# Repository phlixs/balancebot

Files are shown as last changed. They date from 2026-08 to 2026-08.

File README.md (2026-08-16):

# BalanceBot

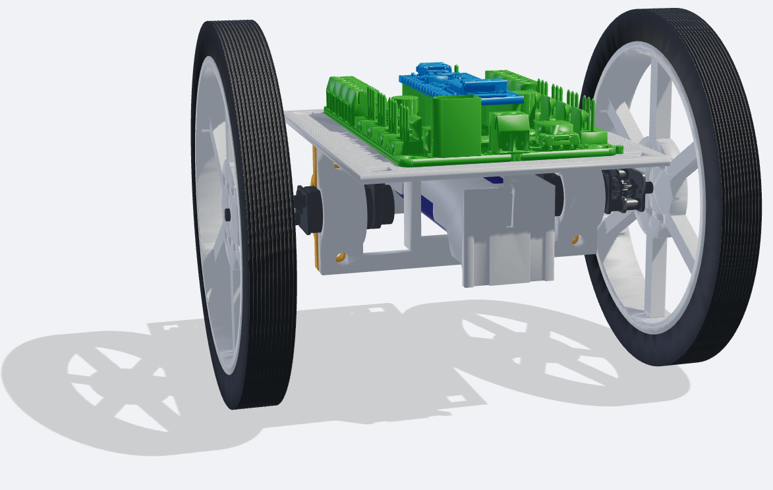
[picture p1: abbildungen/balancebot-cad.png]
Der BalanceBot als CAD-Baugruppe: zwei 90-mm-Räder auf einer Achse, dazwischen der 3D-gedruckte Rahmen mit dem Nano Motor Carrier und dem Arduino Nano 33 IoT auf der Trägerplatte, darunter die Motorhalter mit den N20-Getriebemotoren und dem 18650-Akku.


Ein zweirädriger selbstbalancierender Roboter (inverses Pendel) auf Basis
eines **Arduino Nano 33 IoT** mit **Nano Motor Carrier**.

Die Motivation hinter diesem Projekt ist es, aus den vorhandenen Komponenten
des **Arduino Engineering Kit Rev2** einen vollständig quelloffenen Roboter zu
entwickeln. Wer das Kit besitzt, kann damit den nächsten Schritt gehen und
erhält eine nachhaltige, lizenzunabhängige Engineering-Lösung.

Die Firmware ist in C++ geschrieben und wird mit **PlatformIO** gebaut. Die
Auswertekette ist Python. Der Rahmen ist ein Eigenentwurf in **FreeCAD** und
für den 3D-Druck ausgelegt.

---

## Sicherheit — vor dem ersten Einschalten lesen

Diese Regeln sind nicht kosmetisch. Der Motortreiber des Nano Motor Carrier
ist für **500 mA** ausgelegt, der **Stallstrom der N20-Motoren beträgt
1.03 A**. Ein blockierter Motor bei vollem Duty zerstört den Treiber.

1. **Bei jedem Motortest sind die Räder in der Luft.** Bot aufbocken, so dass
   die Räder frei drehen. Bodenkontakt erst, wenn der Regelkreis am Gerät
   erprobt ist — dann auf freier Fläche und in Bodennähe.
2. **Kein Motorbetrieb ohne erfolgreiche Initialisierung** von Motor Carrier
   und IMU. Schlägt eine davon fehl, bleibt die Firmware im Zustand `E_STOP`
   und gibt keine Stellgröße aus.
3. **Vor jedem Bodenversuch die Akkuspannung prüfen.** Die Stellwirkung
   skaliert direkt mit ihr. Unter **3.3 V** sind die Reglerparameter nicht
   mehr gültig.
4. **`MAX_DUTY` nicht erhöhen.** Die 45 % in `src/balance/config.h` sind die
   Ableitung aus 0.50 A / 1.03 A = 48.5 %, konservativ abgerundet.

### Hartgrenzen in der Firmware

Alle Werte in `Balancebot_code/src/balance/config.h`. Sie sind gerechnet oder
gemessen, nicht geraten:

| Parameter | Wert | Wofür |
|---|---|---|
| `MAX_DUTY` | 45 % | Stromgrenze des Treibers. Überschreiten zerstört ihn. |
| `FALLEN_ANGLE_DEG` | 45° | Sicherheitsabschaltung. Motoren stromlos. |
| `RECOVERY_ANGLE_DEG` | 15° | Rückkehr aus `FALLEN` erst unterhalb dieses Winkels. |
| `SATURATION_TIMEOUT_MS` | 1000 ms | Dauersättigung heißt, der Bot kann sich nicht mehr fangen. |
| `LOOP_OVERRUN_MS` | 50 ms | Ein Zyklus länger als fünf Perioden → die Regelung war blind → `E_STOP`. |
| `IMU_STALE_CYCLES` | 50 (500 ms) | Eingefrorene IMU-Werte → `E_STOP`. |
| `LOOP_PERIOD_MS` | 10 ms | Unterschreiten überläuft das I2C-Budget (6.4 ms Mittel, 8.3 ms worst case). |

### Die gemessenen Parameter gelten für *diesen* Aufbau

Wer den Bot nachbaut, bekommt einen anderen Rahmen, eine andere
Massenverteilung und andere Motoren aus der Serienstreuung. Diese Werte
müssen **neu gemessen**, nicht übernommen werden:

| Parameter | Hier gemessen | Bei falschem Wert |
|---|---|---|
| `DEADZONE_DUTY_POS` / `_NEG` | 23 % / 17 % bei 3.57 V | Schwingen, Gierzucken oder kein Anlaufen |
| `COG_HEIGHT_M` | Schwerpunkthöhe, Auslenkungsmethode | Modell und Verstärkungen falsch ausgelegt |
| `TOTAL_MASS_KG` | gewogen | dito |
| `KP_ANGLE`, `KD_ANGLE` | Polvorgabe aus dem gemessenen Modell, auf Totzeit herabgesetzt | Grenzzyklus oder zu träges Fangen |

Die Asymmetrie der Totzone (23 % vorwärts gegen 17 % rückwärts) liegt am
Treiber des Carriers, nicht am Motor — deshalb wird sie pro Duty-Vorzeichen
kompensiert.

> **Wenn es schwingt, nicht `KD_ANGLE` erhöhen.** Bei totzeitbedingten
> Schwingungen senkt mehr D-Anteil die kritische Totzeit zusätzlich. Der
> übliche Reflex ist hier falsch. `KI_ANGLE` bleibt 0, bis der PD-Regler
> stabil steht.

---

## Hardware

Vollständig aus dem Arduino Engineering Kit Rev2, nichts zugekauft:

| Teil | Typ |
|---|---|
| Mikrocontroller | Arduino Nano 33 IoT (SAMD21) |
| Motortreiber | Arduino Nano Motor Carrier |
| IMU | BNO055, I2C, Sensorfusion auf dem Chip |
| Motoren | 2 × N20-Getriebemotoren, 100:1 |
| Encoder | 2 × magnetisch, 1200 Counts pro Radumdrehung |
| Räder | Pololu, 90 mm |
| Akku | 1 × 18650 Li-Ion, nominal 3.7 V |
| Rahmen | Eigenentwurf, FreeCAD, 3D-Druck |

---

## Aufbau des Repos

```
Balancebot_code/
  src/balance/        Modulare Firmware — aktive Entwicklung
  src/balance.cpp     balance_v1, monolithische Referenzfassung
  src/tests/          Testsketche: hw_check, carrier_timing,
                      imu_latency, deadzone_id
  test/               Native Unit-Tests (Unity, laufen ohne Hardware)
  python/             Messkette: acquire → process → analyze
  messungen/results/  Kuratierte Messprotokolle der Inbetriebnahme
CAD_BalanceBot/       FreeCAD-Baugruppe, STEP-Modelle, CoM-Analyse
```

---

## Werkzeuge einrichten

Gebraucht werden **Python 3.11+** und **PlatformIO**. PlatformIO lädt die
Toolchain für den SAMD21 und die Bibliotheken beim ersten Build selbst.

**Linux**

```bash
python3 -m venv .venv
.venv/bin/pip install platformio
.venv/bin/pip install -r Balancebot_code/python/requirements.txt
```

**Windows (PowerShell)**

```powershell
py -m venv .venv
.venv\Scripts\pip install platformio
.venv\Scripts\pip install -r Balancebot_code\python\requirements.txt
```

---

## Bauen, flashen, beobachten

Alle Firmware-Kommandos laufen **aus `Balancebot_code/`** und sind auf beiden
Plattformen identisch:

| Zweck | Kommando |
|---|---|
| Firmware bauen | `pio run -e balance` |
| Flashen | `pio run -e balance -t upload` |
| Serieller Monitor | `pio device monitor -e balance` |
| Unit-Tests (ohne Hardware) | `pio test -e native` |
| Alle Umgebungen bauen | `pio run -e balance -e balance_v1 -e hw_check -e carrier_timing -e imu_latency -e deadzone_id` |

Unterschiedlich ist nur der serielle Port: Linux `/dev/ttyACM*` — die Nummer
wechselt nach jedem Aus- und Einschalten —, Windows `COM*`. Bei den
Python-Skripten `--port` deshalb immer explizit angeben:

```bash
python Balancebot_code/python/acquire.py --port /dev/ttyACM0   # Linux
```

```powershell
python Balancebot_code\python\acquire.py --port COM3           # Windows
```

> **`-e balance` beim Monitor ist nicht optional.** Ohne Umgebung greift
> `monitor_speed` aus der `[common]`-Sektion nicht, und PlatformIO fällt auf
> 9600 Baud zurück — die Ausgabe ist dann unlesbar.

### Verfügbare Build-Umgebungen

| Umgebung | Was sie tut |
|---|---|
| `balance` | Modulare Regelung, aktiver Stand |
| `balance_v1` | Erste funktionierende PID-Fassung, Referenz |
| `hw_check` | Interaktives Serial-Menü zur Hardware-Prüfung |
| `carrier_timing` | Misst die I2C-Latenz aller Carrier-Aufrufe |
| `imu_latency` | Misst die Dauer eines BNO055-`getEvent()` |
| `deadzone_id` | Rampt Duty hoch und loggt die Anlaufschwelle |
| `native` | Unit-Tests auf dem PC, ohne Hardware |

---

## Erste Inbetriebnahme

**Räder in der Luft.** Der Reihe nach:

1. **Unit-Tests auf dem PC** — `pio test -e native`. Braucht keine Hardware
   und zeigt, ob die Toolchain steht.
2. **`hw_check` flashen** — `pio run -e hw_check -t upload`, dann
   `pio device monitor -e hw_check`. Das interaktive Menü prüft
   Carrier-Version und BNO055-Status (`v`), Motoren einzeln (`m`), Encoder
   (`e`), IMU-Livewerte (`i`) und die Vorzeichen (`d`). `s` ist der Not-Stopp.
3. **Vorzeichen festhalten.** Erwartet wird, mit „vorwärts“ = USB-Richtung:
   Roh-Pitch 0 bei aufrecht und **positiv beim Vorwärtskippen**, vorwärts
   `M1(+duty)` und `M2(-duty)`, Encoder 1 hoch und Encoder 2 runter. Stimmt
   ein Vorzeichen nicht, wird es in `config.h` korrigiert — nicht im Regler
   kompensiert.
4. **Totzone messen** — `deadzone_id` flashen, mitschneiden, auswerten. Die
   Werte in `config.h` eintragen.
5. **Schwerpunkthöhe und Trägheit bestimmen**, dann die Verstärkungen aus dem
   Modell auslegen. `python/system_id.py` rechnet das Streckenmodell.
6. **Erst dann** `balance` flashen — weiterhin mit den Rädern in der Luft.

Die Reihenfolge ist keine Empfehlung: Jeder Schritt validiert die Annahmen
des nächsten. Wer die Totzone überspringt, tunt anschließend gegen ein
Verhalten, das gar nicht vom Regler kommt.

---

## Lizenz

[MIT](LICENSE) — Nutzung, Änderung und Weitergabe sind frei, solange der
Copyright-Vermerk erhalten bleibt. Die Software kommt ohne Gewähr; das
gilt ausdrücklich auch für die Sicherheitsgrenzen oben, die für **diesen**
Aufbau ermittelt wurden.

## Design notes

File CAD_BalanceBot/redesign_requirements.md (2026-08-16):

# Karosserie-Neugestaltung — Anforderungen

Stand 2026-08-09. Gesammelte Anforderungen für die nächste Rahmenversion,
abgeleitet aus Messungen und dem Regelungsmodell (`dokumentation/auslegung/system_model.md`).

---

## Ausgangslage

Die CAD-Baugruppe (`BalanceBotAssembly.FCStd`, Analyse 2026-04-12) ist **nicht**
identisch mit dem physisch aufgebauten Bot. Bekannte Abweichungen:

| Größe | CAD | physisch | Quelle |
|---|-----|---|---|
| Gesamtmasse (mit Rädern) | 155.6 g | **190 g** | gewogen 2026-08-09 |
| Räder, beide zusammen | 67.3 g | **44 g** | gewogen 2026-08-09 |
| Körpermasse ohne Räder | 88.3 g | **146 g** | Differenz |
| Oberkante Nano über Achse | ~29 mm | **42 mm** | gemessen 2026-08-09 |

Der Körper ist also um zwei Drittel schwerer als im CAD und die Räder um ein
Drittel leichter. Ein Nachpflegen der alten Baugruppe lohnt nicht, weil die
neue Karosserie ohnehin eine andere Massenverteilung bekommt. Die Zahlen stehen
hier nur, damit klar ist: **CAD-Werte der alten Baugruppe taugen nicht als
Messwerte.** Das gilt ausdrücklich auch für den CoG-Prior von 8.6 mm — der ist
aus derselben Baugruppe abgeleitet und wartet auf die Messung aus Phase 4.

---

## A1 — Schwerpunkt höher legen — **ZURÜCKGESTELLT nach Messung 2026-08-09**

**Diese Anforderung stand auf einer falschen Prämisse.** Der Schwingversuch
(`Balancebot_code/messungen/results/phase4_swing_20260809.md`, Entscheidung in
[ADR-0008](../dokumentation/entscheidungen/0008-measured-pole-over-estimated-inertia.md)) hat den
instabilen Pol direkt gemessen: **p = 12.1 1/s statt der modellierten 30.1**.
Die Verdopplungszeit beträgt 57 ms, nicht 23 ms — die Regelung hat 5.7
Abtastschritte pro Verdopplung, nicht 2.3. Die Zeitnot, die A1 begründet hat,
existiert nicht.

### Warum Ballast in geringer Höhe sogar schadet

Der ursprüngliche Gedankengang war: Schwerpunkt höher legen heißt längeres
Pendel heißt mehr Reaktionszeit. Das gilt für ein *Fadenpendel*, bei dem die
gesamte Masse am Ende sitzt. Ein Bot ist kein Fadenpendel.

Fügt man dem Körper eine Zusatzmasse m_a in der Höhe h über der Achse hinzu,
ändern sich Zähler und Nenner des Pols unterschiedlich schnell:

```
p^2 = (m*g*L + m_a*g*h) / (J + m_a*h^2)
```

| Symbol | Beschreibung | Einheit |
|---|---|---|
| p | instabiler Pol des aufrechten Bots | 1/s |
| m | bisherige Körpermasse ohne Räder, 0.146 | kg |
| L | bisherige CoG-Höhe über der Achse | m |
| J | bisheriges Trägheitsmoment um die Achse, gemessen 875 g·cm² | kg·m² |
| m_a | zugefügte Ballastmasse | kg |
| h | Höhe des Ballasts über der Achse | m |

Das rückstellende Schweremoment im Zähler wächst **linear** mit h, das
Trägheitsmoment im Nenner **quadratisch**. Für kleines h dominiert der Nenner
den Zähler noch nicht — solange `m_a·h² ≪ J`, bringt der Ballast fast keine
zusätzliche Trägheit, aber auch kaum Hebel. Genau dazwischen liegt ein Bereich,
in dem er netto **schadet**.

Der Umschlagpunkt liegt dort, wo der Ballast das vorhandene J zu dominieren
beginnt, also bei `h ≈ √(J/m_a)`. Mit den gemessenen J = 875 g·cm² = 87500 g·mm²
und m_a = 40 g sind das rund **47 mm**. Erst deutlich darüber greift die
Fadenpendel-Intuition, und im Grenzfall `m_a·h² ≫ J` geht p² → g/h, also
t₂ ∝ √h — um t₂ zu verdoppeln, braucht es die *vierfache* Höhe.

Gerechnet auf der gemessenen Basis (m = 146 g, L = 9 mm, J = 875 g·cm²):

| Ballast | Höhe über Achse | L_neu | t₂ | Gewinn |
|---:|---:|---:|-----:|---:|
| 40 g | 50 mm | 17.8 mm | 53 ms | **0.92×** (schlechter) |
| 40 g | 100 mm | 28.6 mm | 67 ms | 1.16× |
| 40 g | 150 mm | 39.3 mm | 81 ms | 1.41× |
| 60 g | 150 mm | 50.1 mm | 83 ms | 1.43× |

Die frühere Empfehlung „L auf 30 mm, also 40 g auf 10 cm" hätte demnach
16 % mehr Reaktionszeit gebracht — für einen kompletten Karosserieumbau.

**Reihenfolge:** Erst L per Knife-Edge messen, Gains aus dem gemessenen Pol
rechnen, Tuning-Sitzung fahren. Diese Anforderung nur wieder aufgreifen, wenn
sich dabei die Reaktionszeit nachweislich als limitierend erweist — und dann
mit Zielhöhe ≥ 150 mm statt 30 mm, weil darunter der Aufwand den Effekt nicht
rechtfertigt.

Die ursprüngliche Herleitung bleibt zur Nachvollziehbarkeit stehen. Sie beruht
durchgehend auf `J = 1.2·m·L²`, was am Bot als Faktor 6 zu klein nachgewiesen
wurde. Alle t₂- und θ_max-Werte darin sind entsprechend falsch.

<details>
<summary>Ursprüngliche Fassung (überholt, Punktmasse-Annahme)</summary>

**Zielwert: L = 25–35 mm, Auslegungspunkt 30 mm.**

| Symbol | Beschreibung | Einheit |
|---|---|---|
| L | Höhe des Körper-Schwerpunkts über der Radachse | mm |
| p | instabiler Pol des aufrechten Bots, √(m·g·L/J) | 1/s |
| t₂ | Verdopplungszeit des Kippfehlers, ln2/p | ms |
| θ_max | statisch haltbarer Kippwinkel bei 45 % Duty | ° |

Aktuell liegt L bei etwa 9 mm (CAD-Prior 8.6 mm, empirische Gegenprobe aus der
beobachteten Grenzzyklusfrequenz 9.1–9.7 mm). Daraus folgt t₂ ≈ 23 ms — bei
10 ms Regeltakt bleiben der Regelung **2.3 Abtastschritte pro Verdopplung des
Kippfehlers**, und davon geht laut Phase-1-Messung fast ein ganzer Schritt für
die I2C-Kommunikation drauf (6.4 ms mean, 8.3 ms worst case). Das ist kein
Tuningproblem, sondern ein zu schnelles System für diese Hardware.

| L [mm] | t₂ [ms] | Takte pro t₂ | θ_max [°] |
|---:|---:|---:|---:|
| 9 (aktuell) | 23 | 2.3 | 27.3 |
| 20 | 34 | 3.4 | 12.3 |
| 25 | 38 | 3.8 | 9.8 |
| **30** | **42** | **4.2** | **8.2** |
| 35 | 45 | 4.5 | 7.0 |
| 40 | 48 | 4.8 | 6.1 |
| 60 | 59 | 5.9 | 4.1 |

Das Fenster 25–35 mm ergibt sich aus zwei gegenläufigen Effekten: Nach oben
begrenzt der drehmomentbegrenzte Kippwinkel θ_max ∝ 1/L, der bei etwa **41 mm**
unter das ±6°-Auto-Arm-Fenster fällt. Nach unten begrenzt die Reaktionszeit.
Dazwischen ist der Gewinn am größten — von 9 auf 30 mm verdoppelt sich t₂
nahezu, während θ_max mit 8.2° noch komfortabel über dem Arbeitsbereich liegt.
Oberhalb von 35 mm wächst t₂ nur noch schwach (ω₀ geht mit 1/√L), kostet aber
weiter Winkelreserve — und ab 41 mm reicht das Drehmoment nicht mehr, um den
Bot aus dem Auto-Arm-Fenster heraus zu fangen.

**Konstruktive Hebel** — nötige Ballasthöhe über der Achse, um L von 9 mm auf
den Zielwert zu heben:

| Ziel L | mit 20 g | mit 40 g | mit 60 g |
|---:|---:|---:|---:|
| 25 mm | 142 mm | 83 mm | 64 mm |
| 30 mm | 183 mm | **107 mm** | **81 mm** |
| 40 mm | 266 mm | 153 mm | 115 mm |

Der Akku allein (22 g) reicht nicht — er müsste auf 18 cm, das wird ein
wackliger Mast. Realistischer ist, Motor Carrier und Nano (zusammen ~24 g)
mit nach oben zu nehmen und gezielt Ballast zu ergänzen, oder gleich mit
rund 40 g auf 11 cm zu planen.

*Die Tabelle geht von L = 9 mm als Ausgangswert aus (CAD-Prior). Sobald die
Messung aus Phase 4 vorliegt, mit dem echten Startwert neu rechnen.*

</details>

**Nebenwirkung beachten:** Zusätzliche Masse erhöht J und damit den
Drehmomentbedarf. Jeden Entwurfskandidaten vorher durch
`python3 Balancebot_code/python/system_id.py --L-mm <Wert>` schicken.

---

## A2 — Definierter Endanschlag für den Akku

**Der Akku muss in y-Richtung formschlüssig arretiert sein.**

Aktuell wird der 18650 eingeschoben, ohne dass ein Anschlag seine Endlage in
Fahrtrichtung definiert. Die y-Position ist damit nicht reproduzierbar — und
genau diese Position bestimmt den Gleichgewichts-Setpoint.

Rechnung: Der Akku wiegt 22 g von 146 g Körpermasse, also 15 %. Verschiebt er
sich um Δy, wandert der Körperschwerpunkt um 0.15·Δy mit. Der nötige
Setpoint-Trim ist Sp = atan(y/L):

| Akku-Verschiebung Δy | CoG-Versatz | ΔSp bei L = 9 mm | ΔSp bei L = 30 mm |
|---:|---:|---:|---:|
| 2 mm | 0.30 mm | 1.9° | 0.6° |
| 5 mm | 0.76 mm | 4.8° | 1.4° |
| 10 mm | 1.52 mm | 9.6° | 2.9° |

| Symbol | Beschreibung | Einheit |
|---|---|---|
| Δy | Verschiebung des Akkus in Fahrtrichtung | mm |
| Sp | Winkel-Setpoint (Gleichgewichts-Trim) | ° |
| L | CoG-Höhe über der Achse | mm |

Fünf Millimeter Spiel im Akkuschacht sind also bis zu 4.8° Setpoint-Drift.
Zum Vergleich: Das Auto-Arm-Fenster ist ±6° breit, und `TUNE_SP_MAX_DEG`
begrenzt den Trim auf ±15°. Ein Akku, der sich beim Transport verschiebt,
kann den Bot damit allein durch Umlagern unbalancierbar machen — und beim
Debugging sieht das exakt aus wie ein Reglerfehler.

**Diese Anforderung wird durch die Zurückstellung von A1 wichtiger, nicht
unwichtiger.** Ein höherer CoG hätte die Empfindlichkeit um etwa Faktor 3
gedämpft. Da der Bot vorerst bei L ≈ 9 mm bleibt, gilt weiter die linke
Spalte der Tabelle: 5 mm Schachtspiel sind knapp 5° Trimmdrift.

**Anforderung:** Fester Anschlag am Schachtende plus Klemmung oder Federzunge
gegen die Einschubrichtung, sodass die Endlage ohne Zutun des Monteurs
eindeutig ist.

---

## A3 — Referenzflächen fürs Vermessen

Aus der Knife-Edge-Messung 2026-08-09: Die Achslage ließ sich nur über die
Motorwellen abgreifen, und für die Winkelmessung fehlte eine definierte
Bezugsfläche.

Vorschlag: eine plane, zur Radachse parallele Fläche am Rahmen, die als
Auflage beim Kantentest und als Bezug für die Ruhelagenmessung dient. Kostet
nichts und macht jede spätere Vermessung reproduzierbar.

---

## Offene Punkte

- [x] Räder wiegen (2026-08-09: 44 g beide, CAD lag mit 67.3 g deutlich daneben)
- [ ] Zielwert L nach dem Schwingversuch (Phase 4, Messung 3) gegenprüfen —
      der misst den instabilen Pol direkt und ersetzt die J-Schätzung im Modell
- [ ] Entscheiden, ob Ballast oder Umbau der Elektronikebene

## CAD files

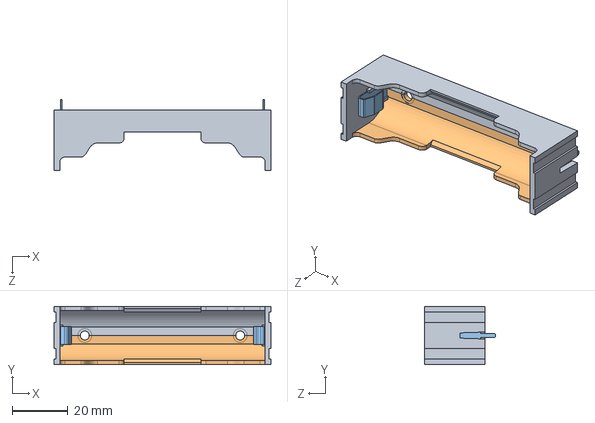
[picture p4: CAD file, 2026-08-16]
CAD_BalanceBot/User Library-18650 Full.STEP
77.6 x 20.8 x 25.5 mm
18650m_1
18650s_По умолчанию x 2

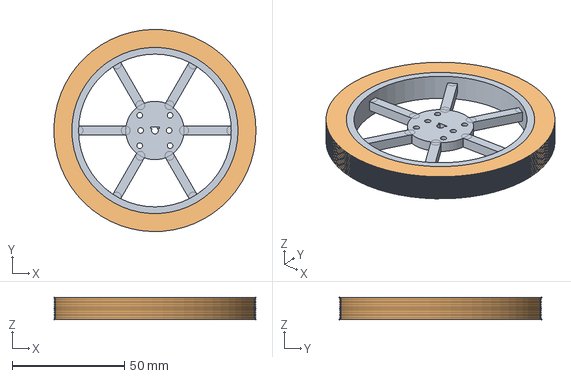
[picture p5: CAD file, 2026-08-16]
CAD_BalanceBot/Pololu_Wheel_90x10.FCStd
89.9 x 90.0 x 10.0 mm
Wheel_Hub
Wheel_Tire

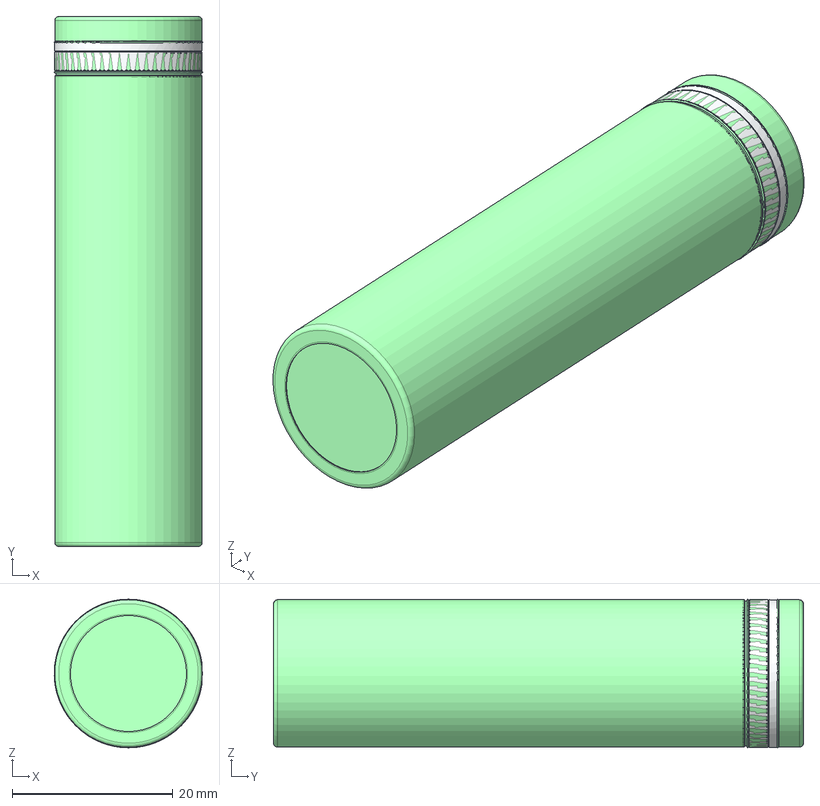
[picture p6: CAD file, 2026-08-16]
CAD_BalanceBot/Samsung INR18650-25R.stp
18.5 x 65.8 x 18.5 mm

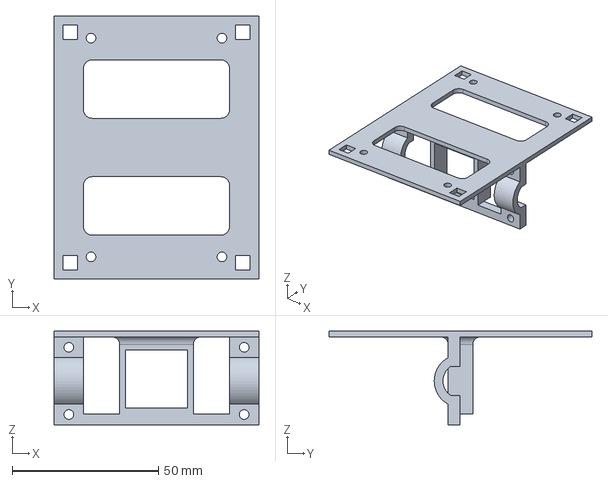
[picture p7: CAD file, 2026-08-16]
CAD_BalanceBot/botframe.FCStd
70.0 x 90.0 x 32.0 mm

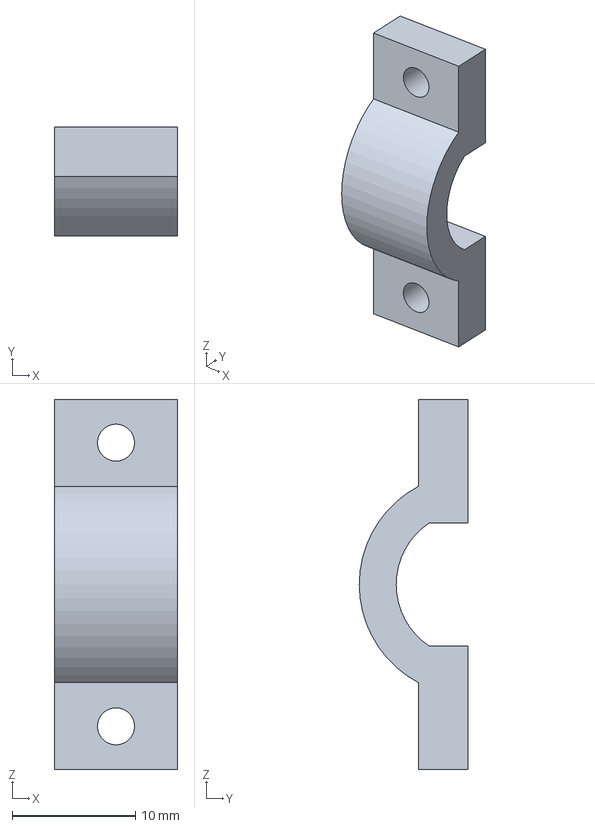
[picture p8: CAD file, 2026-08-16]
CAD_BalanceBot/motorhalter_lose.FCStd
10.0 x 8.80 x 30.0 mm

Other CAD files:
CAD_BalanceBot/Pololu 90mm Wheel.dwg

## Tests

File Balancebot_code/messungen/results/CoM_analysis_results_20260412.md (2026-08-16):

# BalanceBot Center of Mass Analysis

*Created: 12.04.2026 19:30:56*  
*Script: /home/phlix/workspaces/NewBalanceBot_planung/CAD_BalanceBot/CoM_analysis.py*

| Part | Vol [mm3] | Mass [g] | CoM X [mm] | CoM Y [mm] | CoM Z [mm] |
|---|---|---|---|---|---|
| botframe | 13592.7 | 14.14 | 0.00 | -0.78 | -5.17 |
| NANOMotorCarrier | 11434.0 | 21.15 | -0.22 | -4.38 | 4.58 |
| Arduino_Nano33IoT | 1530.2 | 2.83 | -0.02 | -0.50 | 12.89 |
| Battery_18650 | 8205.3 | 22.15 | -0.00 | 0.01 | -9.46 |
| motorhalter_R | 1187.7 | 1.24 | 30.00 | 3.79 | -15.00 |
| motorhalter_L | 1187.7 | 1.24 | -30.00 | 3.79 | -15.00 |
| N20_motor_R | 2838.3 | 12.77 | 29.56 | -0.58 | -13.82 |
| N20_motor_L | 2838.3 | 12.77 | -30.56 | -0.42 | -13.82 |
| Wheel_R_Hub | 10683.0 | 11.11 | 52.90 | -0.60 | -14.70 |
| Wheel_R_Tire | 19596.6 | 22.54 | 52.90 | -0.60 | -14.70 |
| Wheel_L_Hub | 10683.0 | 11.11 | -53.90 | -0.40 | -14.70 |
| Wheel_L_Tire | 19596.6 | 22.54 | -53.90 | -0.40 | -14.70 |
| CoM_Marker | 57.7 | 0.00 | -0.33 | -0.91 | -9.82 |
| **TOTAL** | **103431.3** | **155.58** | | | |

## Summary

| Metric | X [mm] | Y [mm] | Z [mm] |
|---|---|---|---|
| CoM (volume-weighted) | -0.35 | -0.83 | -10.45 |
| CoM (mass-weighted) | -0.33 | -0.91 | -9.82 |

- Wheel axle Z = -14.7 mm
- CoM height above axle: **4.88 mm** (mass-weighted)
- CoM Y offset from axle: **-0.91 mm** (positive = forward)

The coordinate origin is below the botframe base plate. Check the CAD-Assembly-File in FreeCAD to verify

For balancing: the CoM should be ABOVE the wheel axle (high Z) and centered on the axle in Y.

> CoM is **ABOVE** the axle (inverted pendulum, balanceable)

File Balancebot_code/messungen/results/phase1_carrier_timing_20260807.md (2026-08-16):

# Phase 1 — Motor Carrier I2C-Timing (2026-08-07)

**Sketch:** `carrier_timing` (1000 Iterationen pro Aufruf) · **Carrier-FW:** 0.20 · **BNO055-Modus:** NDOF (Default)

## Messwerte

| Aufruf | min [µs] | max [µs] | mean [µs] |
|---|---:|---:|---:|
| `controller.ping()` | 667 | 676 | 668.6 |
| `encoder1.getRawCount()` | 877 | 892 | 884.3 |
| `encoder2.getRawCount()` | 877 | 892 | 884.3 |
| `M1.setDuty(0)` | 667 | 675 | 668.7 |
| `M2.setDuty(0)` | 667 | 676 | 668.8 |
| `bno.getEvent(EULER)` | 948 | 2222 | 1314.4 |
| `bno.getEvent(GYRO)` | 957 | 2259 | 1339.4 |
| **Summe** | **5960** | **8292** | **6428.5** |

## Bewertung

- **Erfolgskriterium erfüllt:** Summe der Mittelwerte 6428.5 µs < 8000 µs (80 % des 10-ms-Budgets bei 100 Hz, ADR-0006). ✓
- Ein voller Regelzyklus (2× IMU-Read, 2× Encoder, 2× setDuty, 1× ping) verbraucht im Mittel **~6.4 ms von 10 ms** allein für I2C-Kommunikation — es bleiben ~3.6 ms für Regler-Rechnung, Logging und Reserve.
- **Achtung, wenig Worst-Case-Reserve:** Die IMU-Reads streuen stark (max 2.2 ms statt 1.3 ms). Im Worst Case aller Aufrufe zusammen: 8292 µs → nur ~1.7 ms Luft. Konsequenzen:
  1. Kein blockierender Code in der Regelschleife (Serial-Prints nur gepuffert, WiFi später non-blocking).
  2. Phase 2 prüft, ob der IMU-Modus (0x08, ohne Magnetometer-Fusion) die IMU-Latenz und ihre Ausreißer reduziert.
  3. `LOOP_PERIOD_MS` unter 10 ms ist definitiv nicht machbar — bestätigt die bestehende Untergrenze.
- Carrier-Aufrufe (ping, setDuty) sind mit ~670 µs sehr konstant (Jitter < 10 µs); die Encoder-Reads ebenso. Die Varianz kommt praktisch nur vom BNO055.

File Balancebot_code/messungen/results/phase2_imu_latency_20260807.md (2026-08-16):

# Phase 2 — BNO055 Latenz & Modus-Entscheidung (2026-08-07)

**Sketch:** `imu_latency` (500 Reads pro Modus, `getEvent(EULER)` mit micros()-Messung) · **Bot:** ruhend, Pitch roh 39.563°

## Messwerte (duration_us eines `getEvent()`-Aufrufs)

| Modus | min [µs] | max [µs] | Verteilung |
|---|---:|---:|---|
| NDOF (Default, 9-DOF-Fusion) | 948 | 2155 | bimodal: ~950 µs und ~1900 µs, Mittel ≈ 1.4 ms |
| IMUPLUS (0x08, 6-DOF ohne Magnetometer) | 941 | 2027 | bimodal: ~942 µs und ~1890 µs, Mittel ≈ 1.4 ms |

*Werte aus Serial-Mitschnitt abgelesen (kein acquire.py-Rohfile); die bimodale
Verteilung entspricht dem BNO055-I2C-Zugriffsmuster (Clock-Stretching).*

## Entscheidung nach Regel aus dem Commissioning-Plan

Regel: Latenz < 5 ms **und** Kalibrierung stabil → NDOF OK; sonst IMU-Modus.

- Latenz: **beide Modi klar unter 5 ms** → kein Ausschlusskriterium.
- Kalibrierung: In Phase 0 zeigte NDOF beim Boot `sys=0, mag=0` (Magnetometer
  unkalibriert). Das Magnetometer sitzt zentimeternah an zwei DC-Motoren, deren
  Spulenströme beim Balancieren ständig wechseln — im NDOF-Modus fließt das
  gestörte Magnetfeld in die Fusion ein und kann Orientierungssprünge verursachen.
- Für die Balance wird nur Pitch (schwerkraftreferenziert) gebraucht; das
  Magnetometer liefert dafür keinerlei Nutzen, nur Risiko.

**→ Entscheidung: IMUPLUS (0x08).** Umgesetzt in `imu.cpp::begin()`
(`setMode(OPERATION_MODE_IMUPLUS)` + 100 ms Wartezeit nach Moduswechsel).

## Einschränkung dieser Messung

`changed=0` in allen 1000 Zeilen: Der Bot stand während des Tests still, der
Pitch blieb LSB-stabil (Auflösung 0.0625°) — die **effektive Datenrate (ODR)
konnte so nicht gemessen werden**. Falls relevant, Test mit leicht bewegtem Bot
wiederholen; ansonsten wird die reale Datenrate beim Phase-C-Logging sichtbar
(process.py erkennt Wiederholwerte).

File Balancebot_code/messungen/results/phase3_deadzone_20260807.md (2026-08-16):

# Phase 3 — Motor-Totzone-Identifikation (2026-08-07)

**Sketch:** `deadzone_id` (Sweep 0→45 % in 1-%-Schritten, 200 ms Setzzeit, 5-fach-Mittelung)
**Bedingungen:** Batteriespannung **3.57 V** (Ersatzzelle), Räder in der Luft, beide Motoren gleichzeitig
**Rohdaten:** `deadzone_20260807_114836.csv` (NextCloud raw/) · Plot: `phase3_deadzone_20260807.png`

## Anlaufpunkte (erster Duty mit Encoder-Bewegung)

| Motor | Duty-Vorzeichen am Motor | Bot-Richtung | Anlauf bei |
|---|---|---|---:|
| M1 (links)  | +duty | vorwärts | **23 %** |
| M1 (links)  | −duty | rückwärts  | **16 %** |
| M2 (rechts) | −duty | vorwärts | **17 %** |
| M2 (rechts) | +duty | rückwärts  | **23 %** |

## Beobachtungen

1. **Die Totzone ist deutlich größer als die bisherige Schätzung** (10 % in
   `config.h`): Worst Case 23 %, Best Case 16 %.
2. **Systematische Asymmetrie nach Duty-Vorzeichen, nicht nach Motor:** Beide
   Motoren laufen auf der positiven Duty-Seite bei 23 % an, auf der negativen
   bei 16–17 %. Das deutet auf eine Asymmetrie im Carrier-Treiber (H-Brücke/
   PWM-Ansteuerung) hin, nicht auf Motorreibung.
3. **Spannungsabhängigkeit:** Gemessen bei 3.57 V. Bei vollem Akku (4.2 V)
   skaliert der Anlauf-Duty grob mit dem Spannungsverhältnis → erwartet ~19–20 %
   Worst Case. Für Phase E/F ist eine spannungs­kompensierte Totzone sinnvoll
   (der Carrier kann die Batteriespannung messen).
4. **Einheiten-Hinweis Pipeline:** `getCountPerSecond()` des Carriers liefert
   offenbar Counts pro 10-ms-Tick, nicht Counts/s — Abgleich mit den
   Rohzähler-Differenzen aus dem hw_check-Motortest ergibt Faktor ~100.
   Für die Totzonen-Bestimmung irrelevant (nur der Anlaufpunkt zählt).

## Entscheidung (freigegeben 2026-08-07)

**Getrennte Kompensation pro Duty-Vorzeichen**, angewendet pro Motor-Anschluss
(`deadzone.h`, aufgerufen in `motor.cpp::_applyToMotors`):

```
DEADZONE_DUTY_POS = 23    DEADZONE_DUTY_NEG = 17
duty > 0 und duty < POS  → auf +POS anheben
duty < 0 und |duty| < NEG → auf −NEG anheben
```

| Symbol | Beschreibung | Einheit |
|---|---|---|
| DEADZONE_DUTY_POS | Anlaufpunkt der positiven Duty-Seite (beide Motoren) | % Duty |
| DEADZONE_DUTY_NEG | Anlaufpunkt der negativen Duty-Seite (Maximum beider Motoren) | % Duty |
| duty | Befehl am einzelnen Motor-Anschluss nach Richtungs-Mapping | % Duty |

**Warum nicht ein symmetrischer Wert:** Bei Vorwärtsfahrt liegt M1 auf der
positiven (23 %) und M2 auf der negativen Seite (17 %). Eine gemeinsame
Schwelle (z. B. 20) hätte bei kleinen Befehlen nur jeweils ein Rad anlaufen
lassen → Gieren und halbes Drehmoment genau im Arbeitsbereich des Reglers.
Exakte Anhebung auf den gemessenen Anlaufpunkt je Seite vermeidet das ohne
Überkompensation.

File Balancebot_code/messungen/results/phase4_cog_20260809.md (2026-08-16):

# Phase 4, Messung 1 — CoG-Höhe L per Auslenkung (2026-08-09)

**Verfahren:** Auslenkungsmethode. Der Bot hängt an den Motorwellen auf zwei
Pfeilern; eine bekannte Masse an bekanntem Hebel dreht ihn um φ. Die klassische
Schneidenmethode ist an diesem Bot geometrisch unmöglich — Begründung in
`../../../dokumentation/inbetriebnahme/commissioning_plan.md`, Panel 3 der Skizze.

**Winkel nicht per Foto, sondern per Lineal.** Statt φ photogrammetrisch zu
bestimmen, wurden die Höhen der beiden Rahmenkanten über dem Boden gemessen —
in Ruhelage und ausgelenkt. Aus der Höhendifferenz über die bekannte
Rahmenlänge folgt der Winkel. Das ist genauer als das Foto (größere Basis,
kein Perspektivfehler) und braucht keine Kameraausrichtung.

---

## Messwerte

| Größe | Wert |
|---|---|
| Zusatzmasse m_a | 36 g |
| Pfeilerhöhe | 122 mm (+ 1.5 mm Wellenradius → Achse bei 123.5 mm) |
| Rahmenlänge (Fahrtrichtung) | 90 mm |
| Anhängepunkt | Schraubenloch, 7.5 mm vom Fahrtrichtungsrand |
| Kantenhöhe **Ruhe** | vorn 105 mm, hinten 110 mm |
| Kantenhöhe **ausgelenkt** | vorn 85 mm, hinten 140 mm |

Aus den Höhendifferenzen über 90 mm Basis:

```
alpha_ruhe  = arcsin( 5/90) =  3.18 Grad
alpha_ausg  = arcsin(55/90) = 37.67 Grad
phi         = alpha_ausg - alpha_ruhe = 34.49 Grad
```

| Symbol | Beschreibung | Einheit |
|---|---|---|
| alpha | Neigung der Rahmenplatte gegen die Waagerechte | ° |
| phi | Auslenkung des Bots durch die Zusatzmasse | ° |

## Zwischenschritt: Lage der Rahmenplatte relativ zur Achse

Die vier Kantenhöhen bestimmen die Plattenlage vollständig, denn beide Kanten
sind starr mit dem Bot verbunden und drehen um dieselbe Achse. Aus dem
Mittelwert der Kantenhöhen in beiden Zuständen folgt für die Plattenmitte:

```
x = +3.87 mm (nach hinten),   y = -16.00 mm (unter der Achse)
```

**Gegenprobe:** Mit diesen Werten zurückgerechnet ergeben sich die Kantenhöhen
105.0 / 85.0 mm (vorn) und 110.0 / 140.0 mm (hinten) — exakt die Messwerte.
Die Geometrierekonstruktion ist damit konsistent.

Daraus die Lage des Anhängepunkts (Schraubenloch) relativ zur Achse in der
Ruhelage: **33.6 mm waagerecht, 18.1 mm senkrecht darunter.**

## Ergebnis

```
tan(phi) = m_a * p_perp / (m * L + m_a * p_par)
L        = m_a * (p_perp/tan(phi) - p_par) / m
```

| Symbol | Beschreibung | Einheit |
|---|---|---|
| p_perp | Hebel des Anhängepunkts quer zur Schwerkraftrichtung (Ruhelage) | mm |
| p_par | Abstand des Anhängepunkts längs der Schwerkraftrichtung | mm |
| m | Körpermasse ohne Räder, 146 | g |
| m_a | Zusatzmasse, 36 | g |
| L | CoG-Höhe über der Radachse | mm |

**L = 7.6 ± 0.9 mm** (Monte-Carlo über alle Eingangsgrößen, 12 %)

Fehlerbeiträge einzeln:

| Quelle | angenommene Streuung | Beitrag auf L |
|---|---|---:|
| Kantenhöhen | ±1 mm je Ablesung | **±0.80 mm** |
| Rahmenlänge | ±1 mm | ±0.32 mm |
| Pfeilerhöhe | ±2 mm | ±0.27 mm |
| Lochlage s | ±0.5 mm | ±0.17 mm |
| Massen | ±0.5 g / ±1 g | ±0.12 mm |

Die Kantenhöhen dominieren, weil der Winkel aus ihrer *Differenz* folgt und
sich die Ablesefehler dort addieren. Wer genauer will, misst die Höhen mit
einem Anschlagwinkel statt freihändig — oder vergrößert die Auslenkung durch
mehr Zusatzmasse.

## Damit ist das Modell vollständig gemessen

| Größe | Wert | Quelle |
|---|---|---|
| m (gesamt, mit Rädern) | 190 g | gewogen |
| m_wheels | 44 g | gewogen |
| m_body | 146 g | Differenz |
| p (instabiler Pol) | 12.14 1/s | Schwingversuch |
| L | 7.6 mm | diese Messung |
| **J** | **739 g·cm²** | = m·g·L/p², Trägheitsradius 22.5 mm |

Nur das Stellmoment bleibt eine Datenblatt-Näherung (Stall-Modell).

**Reglerauslegung** (`python/system_id.py --L-mm 7.6 --pole 12.14`):

| Größe | Wert | bei L = 6.7 … 8.5 mm |
|---|---|---|
| Kp | **6.96** %/° | 6.13 … 7.78 |
| Kd | **0.321** %/(°/s) | 0.283 … 0.359 |
| Sättigungswinkel | 6.5° | 7.3 … 5.8 |

Zum Vergleich die bisherigen Firmware-Startwerte Kp = 2.0 / Kd = 0.1 — der
P-Anteil war um Faktor 3.5 zu weich, der D-Anteil um Faktor 3.2.

## Setpoint-Trim

Die Rahmenplatte steht in der hängenden Ruhelage **3.18°** gegen die
Waagerechte (vorn tiefer). Da eine 180°-Drehung um die waagerechte Radachse
eine waagerechte Ebene wieder auf eine waagerechte abbildet, gilt derselbe
Betrag im aufrechten Gleichgewicht — mit umgekehrtem Vorzeichen relativ zum
Bot. **Sp ≈ 3.2°**, Vorzeichen am Gerät zu bestimmen.

*Das ersetzt die 7.0° aus der früheren Fotoauswertung
(`phase4_swing_20260809.md`, Abschnitt 7). Die Linealmessung hat die größere
Basis und keinen Perspektivfehler; der Fotowert war mit genau diesem Vorbehalt
versehen worden.*

Verbindlich wird der Trim erst aus der IMU: Bot hängend einschalten,
`hw_check` flashen, `i` drücken, statischen Pitch ablesen — die Abweichung von
180° ist der Trimm, ohne jede geometrische Annahme.

## Offen

- [ ] Sp-Vorzeichen und -Betrag per IMU bestätigen
- [ ] Tuning-Sitzung mit Rädern in der Luft: Kp/Kd per Serial hochfahren,
      erst der am Gerät bestätigte Wert wandert in `config.h`

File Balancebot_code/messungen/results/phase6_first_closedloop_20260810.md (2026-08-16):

# Phase 6 — Erster geschlossener Regelkreis am Boden (2026-08-10)

**Aufbau:** Bot auf dem Boden, Räder montiert, erster Versuch mit den aus dem
gemessenen Modell abgeleiteten Gains. Zwei Varianten gefahren: mit USB-Kabel
(angeleint, mit Aufzeichnung) und frei ohne Kabel.

**Gains:** `Kp=6.96  Ki=0.00  Kd=0.32  Sp=3.20`
(aus `system_id.py --L-mm 7.6 --pole 12.14`, siehe `phase4_cog_20260809.md`)

**Beobachtung am Gerät:** „Ohne Kabel schaukelt er sich sehr auf und fährt
davon. Mit Kabel stößt er auch gegen Gegenstände und stabilisiert sich
darüber. Er schwankt in jedem Fall sehr stark."

---

## Zusammenfassung

Der Versuch hat **zwei voneinander unabhängige Probleme** offengelegt. Sie
haben verschiedene Ursachen und verschiedene Gegenmittel, und man darf sie
nicht gleichzeitig zu beheben versuchen:

1. **Wegfahren** — der Setpoint `Sp=3.20` ist zu groß. Der Regler kommandiert
   dauerhaft Vorwärtsfahrt. Reiner Auslegungsfehler meinerseits.
2. **Starkes Schwanken** — ein Grenzzyklus bei 4.5 Hz. Ursache ist die
   **Totzeit der Regelkette**, die das Modell nicht kennt.

Fortschritt trotzdem: Der Bot blieb **12.3 s durchgehend im Zustand
BALANCING** (272817 → 285077). Alle vorherigen Versuche endeten nach 3–8 s.

---

## Problem 1: Der Setpoint war zu groß

### Befund

In der ruhigen Anfangsphase (272820 … 273840, gut 1 s):

| Größe | Beobachtung |
|---|---|
| Pitch | 0 … +1.5°, im Mittel ≈ +0.9° |
| Duty | durchgehend **positiv**, 15 … 45 |
| Position | 0 → 1575 Counts = **0.371 m in 1.02 s** |

Der Regler fährt also permanent vorwärts. Der Grund steht direkt in der
Reglergleichung:

```
Fehler = Sp - pitch = 3.20 - 0.9 = +2.3 Grad
p-Anteil = Kp * Fehler = 6.96 * 2.3 = 16 % Duty  (dauerhaft, einseitig)
```

| Symbol | Beschreibung | Einheit |
|---|---|---|
| Sp | Winkel-Sollwert (Gleichgewichts-Trim) | ° |
| pitch | gemessener Kippwinkel | ° |
| Kp | P-Verstärkung des Winkelreglers | Duty%/° |

Der Bot versucht, einen Sollwinkel zu halten, der nicht sein Gleichgewicht
ist. Um dort hinzukommen, muss er beschleunigen — und weil er den Winkel nie
erreicht, beschleunigt er immer weiter. Das ist das beobachtete „Wegfahren".

### Warum meine Vorhersage von 3.2° falsch war

Der Wert stammte aus der Ruhelage des hängenden Bots (Phase 4): Die
Rahmenplatte stand dort 3.18° gegen die Waagerechte, und weil eine 180°-Drehung
um die waagerechte Radachse eine waagerechte Ebene wieder auf eine waagerechte
abbildet, gilt derselbe Betrag im aufrechten Gleichgewicht.

Die Argumentation ist geometrisch korrekt — sie beantwortet aber die falsche
Frage. Sie liefert den Winkel der **Rahmenplatte**. Der Regler arbeitet mit dem
Winkel, den die **IMU** meldet, und zwischen beiden liegt der Einbauwinkel des
BNO055 auf dem Motor Carrier. **Dieser Einbauwinkel wurde nie vermessen.**

Ich hatte den Vorbehalt zwar notiert („verbindlich wird der Trim erst aus der
IMU"), aber den Wert trotzdem als Startwert ausgegeben. Bei einem Bot, dessen
Sättigungswinkel 6.5° beträgt, ist ein Setpoint-Fehler von 2.3° kein
Feinheitsproblem, sondern ein Drittel des gesamten Arbeitsbereichs.

### Wie der Trim richtig bestimmt wird

Nicht über Geometrie, sondern über die Daten: **Sp ist dort richtig, wo der
mittlere Duty null wird.** Bleibt der Duty im Mittel positiv, ist Sp zu groß;
bleibt er negativ, zu klein.

Aus dem Mittelwert der Anfangsphase folgt für diesen Aufbau **Sp ≈ +0.7 … +1.0**.

Der D-Anteil stört diese Auswertung nicht: Im quasistationären Mittel ist die
Rate null, also mittelt sich `Kd·rate` heraus. Es zählt allein der P-Anteil.

---

## Problem 2: Grenzzyklus bei 4.5 Hz durch Totzeit

### Befund

Zwischen 274630 und 277710 schwingt der Bot mit klar ausgeprägter Periode.
Ausgezählte Abstände aufeinanderfolgender positiver Umkehrpunkte:

```
240, 220, 200, 220, 200, 210, 190, 200, 210, 230, 230, 250, 230, 250  [ms]
```

Mittelwert **220 ms → 4.5 Hz**. Amplitude ±20 … 25°, Duty nahezu durchgehend
an ±45 — der Steller ist also gesättigt und arbeitet praktisch als Relais.

### Warum das dem Modell widerspricht

Für `Kp=6.96 / Kd=0.32` sagt das lineare Modell (ohne Totzeit) einen gut
gedämpften geschlossenen Kreis voraus:

```
s^2 + b*Kd_rad*s + (b*Kp_rad - a21) = 0
s^2 + 33.9*s + 590.4 = 0
   ->  omega_n = 24.3 rad/s = 3.87 Hz,   zeta = 0.70
```

| Symbol | Beschreibung | Einheit |
|---|---|---|
| a21 | Instabilitätsterm der Strecke, = p² | 1/s² |
| b | Stellwirkung, Radmoment pro Duty-% geteilt durch J | rad/s² pro % |
| Kp_rad, Kd_rad | Verstärkungen in rad-Einheiten | %/rad, %/(rad/s) |
| omega_n | Eigenfrequenz des geschlossenen Kreises | rad/s |
| zeta | Dämpfungsgrad des geschlossenen Kreises | – |

Beobachtet wurde eine **Dauerschwingung**, also ζ ≈ 0 statt 0.70. Die Frequenz
liegt in derselben Größenordnung wie der Entwurf, die Dämpfung ist komplett
verschwunden. Das ist die Signatur von **Phasenverlust**, nicht von falscher
Verstärkung.

### Die Rechnung mit Totzeit

Totzeit T dreht Phase, ohne die Amplitude zu ändern. Die charakteristische
Gleichung wird zu

```
s^2 - a21 + b*(Kp_rad + Kd_rad*s) * exp(-s*T) = 0
```

Marginale Stabilität heißt s = jω. Nach Real- und Imaginärteil getrennt:

```
Im:   Kd_rad*w*cos(w*T) - Kp_rad*sin(w*T) = 0    ->  w*T = atan(Kd_rad*w / Kp_rad)
Re:  -w^2 - a21 + b*(Kp_rad*cos(w*T) + Kd_rad*w*sin(w*T)) = 0
```

Die erste Gleichung liefert die Phase, Einsetzen in die zweite ergibt eine
Gleichung allein in ω. Implementiert in `python/system_id.py`
(`critical_delay()`), Ausgabe bei jedem Lauf.

**Ergebnis für den gefahrenen Entwurf: T_krit = 28.7 ms.**

### Das Totzeitbudget der Kette

| Anteil | Wert | Quelle |
|---|---|---|
| Abtastung | 10.0 ms | `LOOP_PERIOD_MS`, ADR-0006 |
| Halteglied (halbe Periode) | 5.0 ms | Abtast-Halte-Charakteristik |
| I2C-Verkehr | 6.4 ms | Phase-1-Messung, Mittelwert |
| **Summe der bekannten Anteile** | **21.4 ms** | |
| BNO055-Fusionsverzögerung | nicht vermessen | kommt obendrauf |

Die bekannten 21.4 ms liegen bereits bei **75 %** der kritischen 28.7 ms.
Rechnet man die Fusionsverzögerung des BNO055 hinzu — der Sensor filtert und
fusioniert intern, bevor er den Euler-Winkel herausgibt — ist die Grenze
überschritten. Die beobachtete Dauerschwingung ist damit erklärt.

### Warum 4.5 Hz und nicht die vorhergesagten 5.7 Hz

Die lineare Rechnung sagt den Grenzzyklus bei 5.67 Hz voraus, gemessen wurden
4.5 Hz. Der Unterschied ist kein Widerspruch, sondern eine Folge der Sättigung:

Bei ±45 % Anschlag arbeitet der Steller als Relais. Seine **effektive**
Verstärkung ist dadurch kleiner als das eingestellte Kp — die Beschreibungs\-
funktion eines gesättigten Gliedes fällt mit wachsender Amplitude. Und eine
kleinere effektive Verstärkung verschiebt den Grenzzyklus zu **niedrigeren**
Frequenzen (siehe Tabelle unten: Kp 6.96 → 3.5 senkt f von 5.67 auf 4.97 Hz).

Ein gesättigter Grenzzyklus bei 4.5 Hz entspricht also einer effektiven
Verstärkung deutlich unter dem eingestellten Wert — genau das, was man bei
±20° Amplitude und dauerhaftem Anschlag erwartet.

### Die kontraintuitive Konsequenz: **mehr Kd macht es schlechter**

Der Reflex bei einer Schwingung ist, den D-Anteil zu erhöhen. Bei
totzeitbedingten Schwingungen ist das falsch:

| Kp | Kd | T_krit | Grenzzyklus |
|---:|---:|---:|---:|
| 6.96 | 0.32 | 28.7 ms | 5.67 Hz |
| 6.96 | 0.40 | 27.9 ms | 6.74 Hz |
| 6.96 | 0.50 | 25.2 ms | 8.28 Hz |
| 6.96 | 0.60 | **22.3 ms** | 9.91 Hz |

Der D-Anteil ist ein Hochpass: Er hebt die Schleifenverstärkung genau dort an,
wo die Totzeit die Phase schon aufgefressen hat. Bei Kd = 0.60 sinkt die
kritische Totzeit auf 22.3 ms — praktisch auf das bekannte Budget von 21.4 ms.

**Gegen Totzeit hilft nur, die Bandbreite zu senken, also Kp zu reduzieren.**

### Empfohlene Einstellung

| Kp | Kd | T_krit | Reserve | omega_n | zeta | Sättigungswinkel |
|---:|---:|---:|---:|---:|-----:|---:|
| 6.96 | 0.32 | 28.7 ms | 1.34× | 24.3 | 0.70 | 6.5° |
| 5.50 | 0.32 | 32.6 ms | 1.52× | 20.9 | 0.81 | 8.2° |
| **4.50** | **0.32** | **35.8 ms** | **1.67×** | **18.1** | **0.93** | **10.0°** |
| 3.50 | 0.32 | 39.5 ms | 1.85× | 14.9 | 1.13 | 12.9° |
| 3.00 | 0.32 | 41.6 ms | 1.94× | 13.1 | 1.30 | 15.0° |

Die Auswahl ist eine Klemme zwischen zwei Grenzen:

- **Nach unten** braucht der Regler Autorität. Stabilisierung verlangt
  `b·Kp_rad > a21`, also **Kp > 1.39**. Darunter kann er den instabilen Pol
  gar nicht mehr zurückholen. Bei Kp = 3.0 liegt ω_n mit 13.1 rad/s nur noch
  8 % über dem Streckenpol von 12.14 — sehr wenig Marge.
- **Nach oben** frisst die Totzeit die Phasenreserve.

**Vorschlag: Kp = 4.5 bei unverändertem Kd = 0.32.** Das deckt sich mit der
empirischen Regel aus dem Inbetriebnahmeplan (hochfahren bis es zittert, dann
auf 70 % — das wären 0.7 × 6.96 = 4.9) und gibt gleichzeitig 1.67-fache
Totzeitreserve. Fallback bei anhaltender Schwingung: 3.5.

Nebeneffekt: Der Sättigungswinkel wächst von 6.5° auf 10.0°. Der Bot darf sich
also weiter neigen, bevor der Regler am Anschlag steht.

---

## Zwei Störeinflüsse in diesen Daten

### Kollisionen verfälschen die Messung

Zwischen 273840 und 274280 steht der Positionszähler **440 ms lang exakt auf
1575 Counts** — die Räder stehen still, obwohl der Regler 11–17 % Duty
kommandiert. Der Bot war blockiert.

Unmittelbar danach, bei 274510/274520, kommen Ratensprünge von **−110.94 und
−117.81 °/s**, und ab da läuft die große Schwingung. Der Grenzzyklus wurde also
durch einen Anstoß ausgelöst, nicht durch die Regelung allein.

Die Beobachtung „mit Kabel stößt er gegen Gegenstände und stabilisiert sich
darüber" beschreibt keine Stabilisierung, sondern eine Kollision, die
Geschwindigkeit vernichtet. Für belastbare Messungen muss die Fläche frei sein.

### Die Totzonen-Kompensation ist ein Relais um die Null

Unterhalb von 23 % (positiv) bzw. 17 % (negativ) hebt `deadzone.h` jeden
Stellwert auf den Anlaufpunkt an. Bei Kp = 6.96 heißt das: Für Fehler zwischen
0.14° und 3.3° liegt am Motor ein **konstanter** Wert an, unabhängig vom
Winkel. In diesem Band ist der Regler kein P-Regler, sondern ein Relais — und
Relais im Regelkreis erzeugen von sich aus Grenzzyklen.

Das kommt zur Totzeit hinzu. Bei Kp = 4.5 wächst dieses Band auf 5.1°, wird
also **größer**, nicht kleiner. Das ist der Preis der Bandbreitensenkung und
beim nächsten Versuch mit zu beobachten.

---

## Was der Versuch außerdem bestätigt hat

- **Vorzeichenkette in beide Richtungen korrekt.** Pitch negativ (vorwärts
  kippen) → Duty positiv (vorwärts fahren, in den Fall hinein), und umgekehrt.
- **Sicherheitsabschaltung greift.** Der Lauf endete bei Pitch −42.69° kurz vor
  der 45°-Grenze mit `BALANCING --> FALLEN` über den Kippwinkel-Cutoff, nicht
  über den Sättigungs-Timeout.
- **Laufzeit-Tuning funktioniert.** Gains und Setpoint ließen sich im laufenden
  Betrieb setzen; die Rückmeldung über `printParams()` bestätigt jede Änderung.

---

## Offene Punkte

- [ ] Sp datenbasiert bestimmen (Ziel: mittlerer Duty ≈ 0), erwartet +0.7…+1.0
- [ ] Kp auf 4.5 senken, Kd unverändert lassen
- [ ] Lauf auf freier Fläche ohne Hindernisse, mit `acquire.py` aufgezeichnet —
      die bisherige Auswertung beruht auf Auszählen im Terminalmitschnitt
- [ ] **BNO055-Fusionsverzögerung vermessen.** Sie ist der einzige unbekannte
      Posten im Totzeitbudget und entscheidet, wie viel Bandbreite überhaupt
      erreichbar ist. Phase 2 hatte für diesen Fall bereits einen
      Complementary Filter auf dem SAMD21 als Ausweg vorgesehen.
- [ ] Positionsdrift bleibt auch mit korrektem Sp bestehen — ein reiner
      Winkelregler hat keine Positionsrückführung. Das ist Phase 7 und kein
      Tuningfehler.

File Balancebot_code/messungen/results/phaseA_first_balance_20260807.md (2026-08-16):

# Phase A Abnahme (Teil 1) + erster Balancierversuch (2026-08-07)

**Firmware:** `balance` (Headless/Auto-Arm, IMUPLUS, per-Vorzeichen-Totzone, gemessene Vorzeichenkette)
**Aufbau:** Bot auf dem Boden, per USB-Kabel von Hand gesichert (starkes Schwingen). Akku 3.57 V.
**Hinweis Vorgehen:** Bodenkontakt war laut Commissioning-Plan erst ab Phase 5+ vorgesehen —
Versuch verlief glimpflich, weitere Tests wieder mit Rädern in der Luft bis Modell + Tuning stehen.

## Was funktioniert hat (ohne Tastendruck)

1. `CALIBRATING → IDLE` nach IMU-Kalibrierung ✓
2. **Auto-Arm** → `BALANCING` nach Aufrechtstellen ✓
3. **16+ s durchgehend BALANCING** bei exakten 100 Hz (Zeitstempel im 10-ms-Raster,
   kein Loop-Overrun), kein falscher E-STOP ✓
   (der alte Stall-Check hätte hier mehrfach fälschlich ausgelöst — Duty 45 bei
   niedriger Radgeschwindigkeit trat wiederholt auf)
4. **Vorzeichenkette im Regelbetrieb validiert:** Pitch > 0 (rückwärts kippen) →
   Duty < 0 (rückwärts fahren, in den Fall hinein) ✓
5. **Gyro-Fix validiert:** geloggte `pitch_rate` stimmt numerisch mit der
   Ableitung des Pitch überein (Achse gyro.x, Vorzeichen, °/s-Umrechnung korrekt)

## Regelverhalten (ungetunt, wie erwartet schwingend)

- Amplitude wächst von ±1.5° auf ±10–15°, zeitweise ±30°; Periode ~0.5 s
- Duty erreicht periodisch den ±45-Anschlag (Sättigung, aber nie > 1 s am Stück
  → Sättigungs-Timeout griff korrekt nicht)
- Position wandert ~0.5 m und pendelt dann — kein Positionsregler aktiv (gewollt)
- Bot fing sich wiederholt selbst, brauchte aber die Hand am Kabel als Begrenzung

**Ursachen des Schwingens (Behebung = Phase 4/5/C):**
1. Startwerte Kp=2.0 / Kd=0.1 ungetunt (Modellwerte fehlen bis CoG-Messung)
2. D-Anteil nutzt noch die verrauschte numerische Fehler-Ableitung statt der
   Gyro-Rate (TODO in pid.cpp, Phase C)
3. Totzonen-Anhebung (23/17) erzeugt ein Mindest-Drehmoment-Quantum → begünstigt
   Grenzzyklus um den Nullpunkt
4. Gleichgewichts-Setpoint = 0° ist nicht exakt (mechanischer Offset, Trim spaeter)

## Offene Abnahme-Punkte Phase A

- [x] Sturztest (2026-08-07, 2× bestanden, beide Richtungen): Cutoff exakt bei
      ±45° → FALLEN, Motoren aus; bleibt in FALLEN solange schräg; nach
      Aufrichten FALLEN → IDLE → Auto-Arm → BALANCING ohne Tastendruck.
      Sättigungsschutz feuerte korrekt nicht (Duty nur 740 ms < 1 s am
      Anschlag, dann griff der Tilt-Cutoff zuerst).
- [x] Headless-Test (2026-08-07 bestanden): Kaltstart nur mit Akku, komplette
      LED-verifizierte Kette Setup → CALIBRATING → IDLE (mit 20-s-Fallback bei
      unvollstaendiger Accel-Kalibrierung) → Auto-Arm → BALANCING → FALLEN
      (>45°, Motoren aus) → Aufrichten → Re-Arm. Kein PC, kein Tastendruck.

## Phase A: ABGENOMMEN (2026-08-07)

Erkenntnisse fuer die Folgephasen:
- BNO055 verliert Kalibrierung bei Stromverlust → Kalibrierungs-Timeout-Fallback
  eingebaut (20 s, dann nur-Gyro); sauberer Fix = Offsets in FlashStorage (Phase E)
- LED-Zustandsanzeige (LED_BUILTIN) fuer Headless-Diagnose ergaenzt
- Beobachtet am Boden (verfruehte Versuche): Aufschaukeln (ungetunt) UND
  Wegfahren in eine Richtung (Setpoint-Offset, PD ohne Positionsschleife
  integriert konstanten Winkelfehler zu Geschwindigkeit) → Phase C/F/G
- Upload-Auto-Reset (1200 bps) seit USB-Abriss unzuverlaessig; Workaround
  Doppel-Klick-Reset in Bootloader; USB-Kabel pruefen/tauschen

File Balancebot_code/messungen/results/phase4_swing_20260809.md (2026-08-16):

# Phase 4, Messung 3 — Schwingversuch (2026-08-09)

**Ziel:** Den instabilen Pol des Balancierproblems messen, statt ihn aus einer
Trägheitsannahme zu rechnen.

**Reproduzieren:**
```bash
python python/swing_analysis.py --videos <v1.mp4> <v2.mp4> --t-end 14.5 --L-mm 9 \
       --out messungen/results/phase4_swing_20260809.png
python python/rest_angle.py <ruhelage.jpg> \
       --out messungen/results/phase4_restangle_20260809.png
```
Die Rohmedien (2 Videos, 2 Fotos) liegen nach ADR-0002 auf NextCloud, nicht im
Repo. Getrackt sind nur die abgeleiteten Abbildungen.

---

## 1. Warum dieser Versuch überhaupt

Das Systemmodell braucht zwei Größen: die CoG-Höhe L und das Trägheitsmoment J
um die Radachse. L lässt sich mit einer Kante messen. J war bisher **geschätzt**
als `J = 1.2·m·L²` — Punktmasse im Schwerpunktabstand, plus 20 % Zuschlag.

Diese Annahme war verdächtig, weil die Masse des Bots von der Achse bis über
42 mm Höhe reicht und der Beitrag zu J quadratisch mit dem Abstand wächst. Bei
einem Bot, dessen Massen ober- und unterhalb der Achse sich im *ersten* Moment
(dem Schwerpunkt) weitgehend aufheben, im *zweiten* Moment (der Trägheit) aber
gerade nicht, ist die Punktmassennäherung strukturell falsch.

Der Schwingversuch umgeht die Frage: **Hängender und aufrechter Bot haben
denselben Eigenwert-Betrag.** Linearisiert gilt

```
haengend:  theta_dd = -(m*g*L/J) * theta      (stabil, schwingt)
aufrecht:  theta_dd = +(m*g*L/J) * theta      (instabil, kippt)
```

| Symbol | Beschreibung | Einheit |
|---|---|---|
| theta | Auslenkung aus der Ruhe- bzw. Gleichgewichtslage | rad |
| m | Körpermasse ohne Räder, 0.146 | kg |
| g | Erdbeschleunigung, 9.81 | m/s² |
| L | Schwerpunktabstand von der Radachse | m |
| J | Trägheitsmoment des Körpers um die Radachse | kg·m² |

Nur das Vorzeichen dreht sich. Die gemessene Schwingfrequenz **ist** damit der
instabile Pol — ohne dass J bekannt sein muss.

## 2. Aufbau

Räder ab, Bot ausgeschaltet, Akku eingebaut, Kabel in Betriebslage. Beide
Motorwellen auf zwei 3D-gedruckten Pfeilern aufgelegt, Bot pendelt frei um die
echte Radachse im Spalt zwischen den Pfeilern.

Warum die Wellen als Lager: Der Drehpunkt muss die Radachse sein, denn genau
darum dreht der Körper auch im Betrieb. Ein künstlicher Drehpunkt hätte einen
anderen Hebel und damit eine andere Frequenz.

## 3. Auswertemethode und warum so

**Video statt Stoppuhr.** Bei T ≈ 0.5 s verzählt man sich beim Mitzählen von
20 Perioden. Das Video liefert 30 Stützstellen pro Sekunde; die Frequenz kommt
aus dem Spektrum statt aus einer Handzählung.

**Zeitstempel aus dem Container statt Nennframerate.** Handys nehmen häufig mit
variabler Framerate auf, was die Frequenz systematisch verzerrt. Gemessen:
**30.005 fps mit 0.007 ms Streuung** — konstant, kein VFR. Diese Prüfung ist im
Skript fest eingebaut und wird bei jedem Lauf ausgegeben.

**Blaue Rahmenplatte als Marker.** Sie ist die einzige große, sättigungsstarke
Fläche am Bot. Wand (weiß), Pfeiler (neutralgrau), Tisch (braun) und Hand
(Hautton) haben alle B < R — eine Kanalabstandsschwelle (`B > R+25 ∧ B > G+15`)
trennt sie zuverlässig, ohne Modelltraining und ohne Kalibrierung auf die
Belichtung.

**Zwei Signale pro Video.** Ausgewertet werden Schwerpunkt *und*
Hauptachsenwinkel der Maske. Der Schwerpunkt hat die bessere Statistik, der
Winkel ist die physikalisch direkte Größe. Stimmen beide überein, ist das ein
Hinweis, dass die Starrkörperschwingung gemessen wurde und kein Trackingartefakt.
Vier Schätzungen (2 Videos × 2 Signale) ergeben die Streuungsangabe.

**Automatisches Anregungsfenster.** Vor dem Anstoß steht der Bot still oder wird
angefasst. Dieser Teil trägt kein Signal bei, verschlechtert aber das
Nutz-zu-Stör-Verhältnis. Das Skript sucht das Maximum der Einhüllenden — den
Anstoß — und wertet erst ab dort aus, also die freie Ausschwingung. Das allein
hat die Streuung der vier Schätzungen von 4.5 % auf 2.2 % halbiert.

**Parabolische Interpolation des Spektralgipfels.** Ohne sie wäre die Auflösung
bei ~10 s Fenster auf 0.1 Hz begrenzt, also auf 5 %.

## 4. Ergebnis

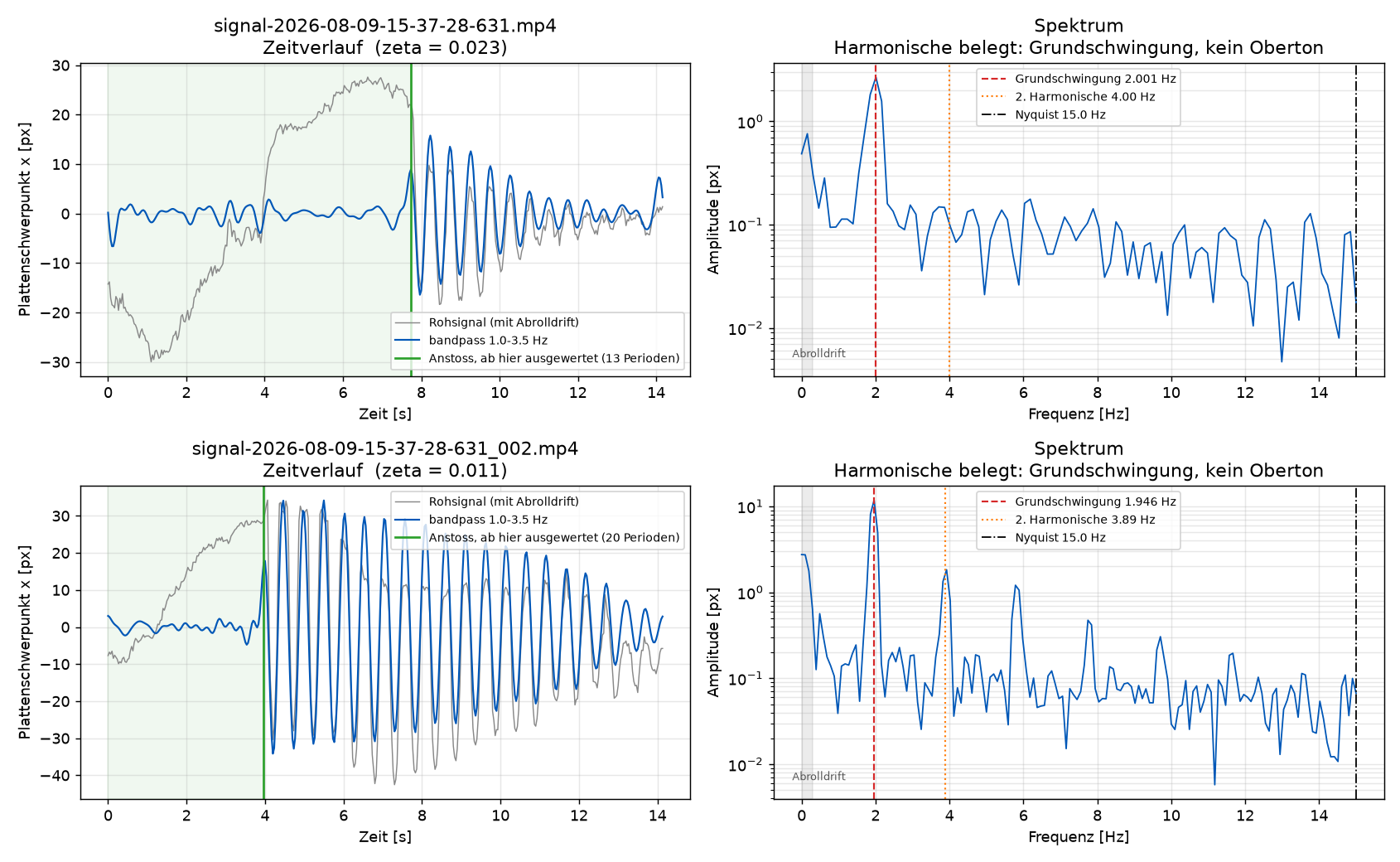
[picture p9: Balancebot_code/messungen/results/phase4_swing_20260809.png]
Schwingversuch


*Links: Zeitverlauf. Grau das Rohsignal mit der langsamen Abrolldrift, blau
bandpassgefiltert, grün der erkannte Anstoß. Rechts: Spektrum mit markierter
Grundschwingung, zweiter Harmonischer und Nyquistgrenze.*

| Größe | Wert |
|---|---|
| Schwingfrequenz f | **1.974 ± 0.043 Hz** (2.2 %, 4 Schätzungen) |
| Schwingungsdauer T | 0.5067 s |
| Pol, roh gemessen | 12.40 1/s |
| **Pol, abrollkorrigiert p** | **12.14 1/s** |
| Zeitkonstante 1/p | 82 ms |
| **Verdopplungszeit t₂** | **57 ms = 5.7 Abtastschritte** bei 10 ms |
| Dämpfungsgrad ζ | 0.011 … 0.028 |

**Aliasing ist ausgeschlossen**, und zwar aus zwei unabhängigen Gründen, die
beide in der rechten Spalte der Abbildung sichtbar sind: Die Grundschwingung
bei 1.97 Hz liegt weit unter der Nyquistgrenze von 15.0 Hz, und bei 3.89 Hz
liegt ein klarer Gipfel — die **zweite Harmonische**. Ein Alias hätte keine
Harmonische an der doppelten Frequenz. Der Gipfel entsteht durch die schwache
Nichtlinearität des Pendels bei endlicher Amplitude.

**Die Dämpfung belegt, dass der Aufbau nicht klemmt.** ζ ≈ 0.02 heißt, die
Amplitude fällt pro Periode um rund 12 %. Bei einer klemmenden Welle wäre die
Schwingung nach wenigen Perioden verschwunden und die Frequenzmessung
unbrauchbar. Der Frequenzfehler durch Dämpfung beträgt ζ²/2 ≈ 0.02 % und ist
vernachlässigbar — die gemessene Frequenz ist die ungedämpfte Eigenfrequenz.

## 5. Fehlerbilanz

| Quelle | Größe | Art | behandelt |
|---|---|-----|---|
| Streuung der 4 Schätzungen | ±2.2 % | zufällig | als Unsicherheit angegeben |
| Abrollen der Welle | −2.1 % | systematisch | herausgerechnet, s. u. |
| Dämpfung ζ ≈ 0.02 | +0.02 % | systematisch | vernachlässigt |
| Amplitude θ₀ ≈ 7° | +0.09 % | systematisch | vernachlässigt |
| Zeitbasis 30.005 fps | <0.03 % | systematisch | vernachlässigt |

### Abrollkorrektur — Herleitung

Die Wellen liegen auf **flachen** Pfeileroberseiten und rollen darauf ab,
statt um ihre Achse zu drehen. *(Am 2026-08-09 am Aufbau bestätigt: Die
3D-gedruckten Pfeiler haben eine glatte, flache Oberseite ohne Nut oder
Schlitz. Die Korrektur gilt also — hätte die Welle in einer Nut gesessen und
sich darin gedreht, wäre der Rohwert p = 12.40 1/s der richtige gewesen.)* Die momentane Drehachse ist die Berührlinie,
also r = 1.5 mm unter der Wellenmitte. Mit Wellenradius r und
Schwerpunktabstand d lautet die Lage des Schwerpunkts beim Abrollen

```
x_c = -r*theta + d*sin(theta)
y_c = -d*cos(theta)
```

Die kinetische Energie wird damit

```
T = 1/2 * theta_dot^2 * [J_c + m*(d*cos(theta) - r)^2 + m*d^2*sin^2(theta)]
```

und für kleine Auslenkungen `T = ½·θ̇²·[J_c + m(d−r)²]`, während
`V = ½·m·g·d·θ²`. Daraus

```
w_roll^2  = m*g*d / (J_c + m*(d-r)^2)        gemessen
w_achse^2 = m*g*d / (J_c + m*d^2)            gesucht
```

J_c eliminiert ergibt die Korrekturformel, die im Skript steht:

```
w_achse^2 = g*d / (g*d/w_roll^2 + 2*d*r - r^2)
```

| Symbol | Beschreibung | Einheit |
|---|---|---|
| r | Radius der Motorwelle, 0.0015 | m |
| d | Schwerpunktabstand von der Wellenachse (= L) | m |
| J_c | Trägheitsmoment um den Schwerpunkt | kg·m² |
| w_roll | gemessene Kreisfrequenz beim Abrollen | 1/s |
| w_achse | gesuchte Kreisfrequenz bei Drehung um die Achse | 1/s |

Das rollende Pendel schwingt **schneller**, weil der effektive Hebel
(d − r) statt d beträgt. Der gemessene Pol ist also zu hoch, die Korrektur
zieht ab. Sie beträgt **−2.1 % und ist praktisch unabhängig von d**
(bei d = 5…30 mm zwischen −1.8 % und −2.1 %) — die Korrektur lässt sich
also anwenden, obwohl L noch nicht gemessen ist.

> **Korrektur einer früheren Aussage:** In der Diskussion war diese
> Fehlerquelle mit „Größenordnung 10 %" beziffert worden. Das war eine
> Bauchschätzung, die eine Drehung um den festen Berührpunkt unterstellte
> statt eines Abrollens. Die Herleitung oben ergibt 2.1 %. Die Richtung
> stimmte — der gemessene Pol fällt zu hoch aus —, die Größe war um Faktor 5
> überschätzt.

**Für die Wiederholung:** Wellen in flache V-Kerben legen. Das unterbindet das
Abrollen, eliminiert die Korrektur und beseitigt zugleich die langsame Drift
(siehe Abschnitt 8).

## 6. Konsequenz für das Modell

| | Modell (J geschätzt) | Messung | Faktor |
|---|---:|---:|---:|
| J bei L = 9 mm | 142 g·cm² | **875 g·cm²** | 6.2 |
| Trägheitsradius √(J/m) | 9.9 mm | **24.5 mm** | 2.5 |
| p | 30.1 1/s | **12.1 1/s** | 0.40 |
| t₂ | 23 ms | **57 ms** | 2.5 |
| Abtastschritte pro t₂ | 2.3 | **5.7** | 2.5 |

Der gemessene Trägheitsradius von 24.5 mm ist physikalisch plausibel: Der
Körper reicht von den Motoren auf Achshöhe bis zur Nano-Oberkante bei 42 mm,
eine mittlere quadratische Entfernung von rund 25 mm liegt genau dazwischen.
Die angenommenen 9.9 mm hätten bedeutet, dass die gesamte Masse dort sitzt, wo
der Schwerpunkt liegt — was hier gerade nicht der Fall ist.

**J bleibt an L gekoppelt:** J = m·g·L/p². Ohne die Knife-Edge-Messung ist J
nur bis auf diesen Faktor bestimmt. Für die Reglerauslegung ist das teilweise
folgenlos, denn Kp hängt gar nicht von p ab:

```
Kp_rad = 5*m*g*L / tau_pro_duty          (unabhaengig von p)
Kd_rad = 2.8*m*g*L / (tau_pro_duty * p)  (faellt mit steigendem p)
```

| Symbol | Beschreibung | Einheit |
|---|---|---|
| Kp_rad | P-Verstärkung in rad-Einheiten | Duty%/rad |
| Kd_rad | D-Verstärkung in rad-Einheiten | Duty%/(rad/s) |
| tau_pro_duty | Radmoment pro Duty-Prozent | N·m/% |

Die Zahlenwerte folgen aus der Polvorgabe ζ = 0.7, ω_c = 2p. Konkret gegenüber
der alten Schätzung: **Kp unverändert 8.24 %/°, Kd von 0.153 auf 0.380 %/(°/s)**
— also 2.5× mehr Dämpfung, weil das System langsamer ist als angenommen.

## 7. Ruhelage (Messung 3a)

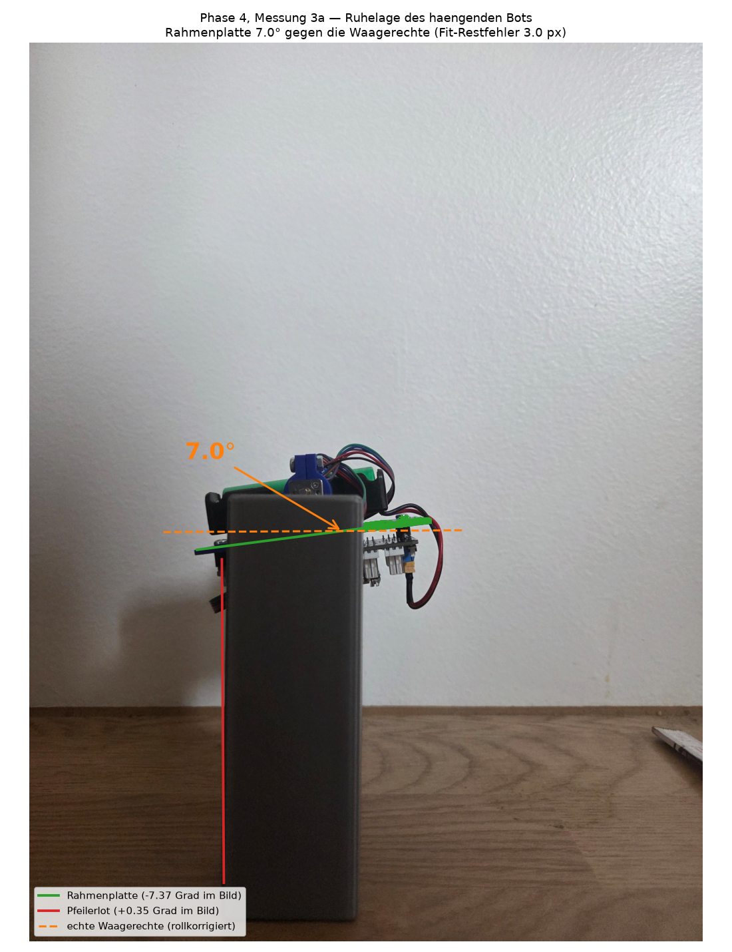
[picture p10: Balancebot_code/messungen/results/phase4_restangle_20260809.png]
Ruhelage


Photogrammetrisch aus dem Standfoto. Zwei Referenzen, beide im Bild:

1. **Das Lot** — die senkrechte Pfeilerkante. Sie liefert den Rollwinkel der
   Kamera (+0.35°) und macht die Messung unabhängig davon, ob das Handy gerade
   gehalten wurde. Ausgewertet wird die Kante mit dem kleineren Restfehler; die
   andere war durch den Wandschatten gestört.
2. **Die Platte** — der Pfeiler verdeckt ihre Mitte, die beiden Enden sind frei
   und definieren die Gerade. Ein blauer Stecker unter dem rechten Ende wird
   verworfen, sonst zieht er den Fit um gut 1° schief.

**Ergebnis: 7.0° gegen die Waagerechte, rechtes Ende höher.** Restfehler des
Fits 3.0 px über 44 Stützstellen; Zwei-Punkt-Fit und spaltenweiser Fit stimmen
auf 0.09° überein.

Warum eine Waagerechte überhaupt die richtige Referenz ist: Eine 180°-Drehung
um die waagerechte Radachse bildet eine waagerechte Ebene wieder auf eine
waagerechte ab. Ist die Platte im aufrechten Gleichgewicht waagerecht, dann ist
sie es im hängenden Gleichgewicht auch — die Abweichung ist dann direkt der
Trimm.

**Vorbehalte, die das Verfahren nicht auflösen kann:**
- Dass die Platte in der Soll-Aufrechtlage tatsächlich waagerecht steht, ist
  nicht verifiziert.
- Dass die Kamera entlang der Radachse ausgerichtet war, ebenso wenig. Eine
  schiefe Blickrichtung verzerrt den scheinbaren Winkel.
- Die Akkulage ist ohne Endanschlag nicht reproduzierbar (siehe
  `CAD_BalanceBot/redesign_requirements.md`, A2). Der Wert gilt nur für die
  Lage zum Messzeitpunkt.

Der Wert taugt damit als **Größenordnung, nicht als Sollwert**.

**Belastbarer Ersatz:** Bot hängend einschalten, `hw_check` flashen, `i`
drücken, statischen Pitch ablesen. Die Abweichung von 180° ist der Trimm —
ohne geometrische Annahme, ohne Kameraausrichtung. Die 5-Hz-Ausgaberate von
`imuLive`, die für die Schwingung unbrauchbar gewesen wäre, reicht für einen
statischen Messwert völlig.
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

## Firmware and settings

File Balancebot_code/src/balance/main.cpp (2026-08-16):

// ============================================================
// main.cpp -- BalanceBot: Modulare Hauptschleife mit Zustandsmaschine
//
// Zustaende: INIT --> CALIBRATING --> IDLE --> BALANCING --> FALLEN --> E_STOP
//
// Headless-Betrieb (Phase A): bootet ohne USB (Serial-Timeout),
// armiert selbststaendig wenn der Bot aufrecht+ruhig hingestellt
// wird (Auto-Arm), SafetySupervisor ueberwacht Tilt / IMU-Stale /
// Loop-Overrun / Saettigung.
//
// Serial-Befehle (ein Zeichen, optional -- alles geht auch headless):
//   's'  --> IDLE nach BALANCING (manueller Start)
//   'q'  --> BALANCING nach IDLE (quit)
//   'r'  --> E_STOP: direkter Neuinitialisierungs-Versuch
//   'h'  --> CSV-Header erneut ausgeben
//   'p'  --> Parameter ausgeben (Kp, Ki, Kd, Setpoint)
//
// TODO: Erweiterung um serielle Parameter-Aenderung (z.B. "Kp=3.5")
// ============================================================

#include <Arduino.h>
#include <SPI.h>
#include <ArduinoMotorCarrier.h>

#include "config.h"
#include "state_machine.h"
#include "imu.h"
#include "motor.h"
#include "encoder.h"
#include "pid.h"
#include "logger.h"
#include "autoarm.h"
#include "safety.h"
#include "command.h"

// ------------------------------------------------------------
// Globale Objekte
// ------------------------------------------------------------

Imu        imu;
MotorPair  motors;
Encoder    enc;

AutoArm autoArm(AUTOARM_ANGLE_DEG, AUTOARM_RATE_DPS, AUTOARM_STABLE_MS);

SafetySupervisor safety(
    FALLEN_ANGLE_DEG, IMU_STALE_CYCLES, LOOP_OVERRUN_MS,
    MAX_DUTY, SATURATION_TIMEOUT_MS
);

// Winkel-PID (innerer Regler)
Pid pidAngle(
    KP_ANGLE, KI_ANGLE, KD_ANGLE, KAW_ANGLE,
    INTEGRAL_MAX_ANGLE,
    -(float)MAX_DUTY, (float)MAX_DUTY
);

// Position-PID (aeusserer Regler -- erst nach stabilem Angle-PD aktivieren)
Pid pidPos(
    KP_POS, KI_POS, KD_POS, KAW_POS,
    20.0f, -MAX_POS_CORRECTION_DEG, MAX_POS_CORRECTION_DEG
);

// ------------------------------------------------------------
// Zustandsmaschine
// ------------------------------------------------------------

State        currentState = State::INIT;
unsigned long fallenStartMs = 0; // Zeitstempel des Eintritts in FALLEN

// Winkel-Sollwert zur Laufzeit trimmbar (Serial "Sp=1.5"), Start aus config.h.
// Gleicht den mechanischen Gleichgewichts-Offset aus, bis der
// Auto-Trim (Phase F) das uebernimmt.
float setpointAngleDeg = SETPOINT_ANGLE_DEG;

// Zustandswechsel mit Logging
void changeState(State next) {
    if (next == currentState) return;
    Logger::printStateChange(currentState, next);
    currentState = next;
}

// ------------------------------------------------------------
// Parameter-Ausgabe fuer Debugging
// ------------------------------------------------------------

void printParams() {
    Logger::printComment("--- Parameter (aenderbar: Kp=/Ki=/Kd=/Sp= + Enter) ---");
    Serial.print("# Kp=");  Serial.print(pidAngle.kp());
    Serial.print(" Ki=");   Serial.print(pidAngle.ki());
    Serial.print(" Kd=");   Serial.print(pidAngle.kd());
    Serial.print(" Sp=");   Serial.println(setpointAngleDeg);
    Serial.print("# MAX_DUTY="); Serial.println(MAX_DUTY);
}

// ------------------------------------------------------------
// Serial lesen (non-blocking):
//   - Einzelzeichen-Befehle (s/q/r/h/p) wirken sofort
//   - alles andere sammelt der Zeilenpuffer bis Enter und wird
//     als Tuning-Befehl geparst ("Kp=3.5", siehe command.h)
// ------------------------------------------------------------

float clampf(float v, float lo, float hi) {
    if (v < lo) return lo;
    if (v > hi) return hi;
    return v;
}

void applyTuneCommand(const TuneCommand& tc) {
    switch (tc.key) {
        case TuneKey::KP:
            pidAngle.setKp(clampf(tc.value, 0.0f, TUNE_KP_MAX));
            break;
        case TuneKey::KI:
            pidAngle.setKi(clampf(tc.value, 0.0f, TUNE_KI_MAX));
            break;
        case TuneKey::KD:
            pidAngle.setKd(clampf(tc.value, 0.0f, TUNE_KD_MAX));
            break;
        case TuneKey::SP:
            setpointAngleDeg = clampf(tc.value, -TUNE_SP_MAX_DEG, TUNE_SP_MAX_DEG);
            break;
        default:
            Logger::printComment("Unbekannter Befehl. Format: Kp=3.5 / Ki= / Kd= / Sp=");
            return;
    }
    printParams();
}

bool isImmediateCommand(char c) {
    return c == 's' || c == 'q' || c == 'r' || c == 'h' || c == 'p';
}

char readSerialCommand() {
    static char    lineBuf[24];
    static uint8_t lineLen = 0;
    char immediate = '\0';

    while (Serial.available() > 0) {
        char c = (char)Serial.read();
        if (c == '\n' || c == '\r') {
            if (lineLen > 0) {
                lineBuf[lineLen] = '\0';
                applyTuneCommand(parseTuneCommand(lineBuf));
                lineLen = 0;
            }
        } else if (lineLen == 0 && isImmediateCommand(c)) {
            immediate = c;
        } else if (lineLen < sizeof(lineBuf) - 1) {
            lineBuf[lineLen++] = c;
        } else {
            lineLen = 0; // Overflow: Zeile verwerfen
        }
    }
    return immediate;
}

// ------------------------------------------------------------
// Uebergangs-Helfer
// ------------------------------------------------------------

// ------------------------------------------------------------
// LED-Zustandsanzeige (headless Diagnose, LED_BUILTIN)
//   Setup laeuft:  dauerhaft an (bis Zustandsmaschine uebernimmt)
//   CALIBRATING:   schnelles Blinken (10 Hz)
//   IDLE:          langsames Blinken (1 Hz)
//   BALANCING:     dauerhaft an
//   FALLEN:        Doppelblitz pro Sekunde
//   E_STOP:        kurzer Einzelblitz alle 2 s
// ------------------------------------------------------------

void updateStateLed(unsigned long nowMs) {
    bool on = false;
    unsigned long phase = nowMs % 1000;
    switch (currentState) {
        case State::CALIBRATING: on = (nowMs / 50) % 2;  break;
        case State::IDLE:        on = (nowMs / 500) % 2; break;
        case State::BALANCING:   on = true;              break;
        case State::FALLEN:
            on = (phase < 100) || (phase >= 200 && phase < 300);
            break;
        case State::E_STOP:      on = (nowMs % 2000) < 100; break;
        default:                 on = false;             break;
    }
    digitalWrite(LED_BUILTIN, on ? HIGH : LOW);
}

// Regler-Zustand loeschen und Balancieren starten (aus IDLE)
void startBalancing() {
    pidAngle.reset();
    pidPos.reset();
    enc.reset();
    motors.resetStall();
    safety.reset();
    changeState(State::BALANCING);
}

// Peripherie neu initialisieren (aus E_STOP/INIT per 'r')
bool tryReinit() {
    motors.stop();
    motors.resetStall();
    enc.reset();
    pidAngle.reset();
    pidPos.reset();
    return controller.begin() && imu.begin();
}

// ------------------------------------------------------------
// Setup
// ------------------------------------------------------------

void setup() {
    // LED sofort an: "Strom da, setup laeuft" -- headless sichtbar
    pinMode(LED_BUILTIN, OUTPUT);
    digitalWrite(LED_BUILTIN, HIGH);

    Serial.begin(SERIAL_BAUD);
    // Begrenzt auf Serial warten -- ohne USB-Host bootet die Firmware
    // nach SERIAL_WAIT_MS headless weiter (Phase A)
    unsigned long serialWaitStart = millis();
    while (!Serial && (millis() - serialWaitStart) < SERIAL_WAIT_MS) {
        delay(10);
    }

    Logger::printComment("BalanceBot startet...");

    // Motor Carrier initialisieren
    if (!controller.begin()) {
        Logger::printComment("FEHLER: Motor Carrier nicht gefunden!");
        changeState(State::E_STOP);
        return;
    }
    controller.reboot();
    delay(500);
    motors.begin();
    enc.begin();

    // IMU initialisieren
    if (!imu.begin()) {
        Logger::printComment("FEHLER: BNO055 nicht gefunden!");
        motors.stop();
        changeState(State::E_STOP);
        return;
    }

    // Initialisierung erfolgreich --> Kalibrierung starten
    changeState(State::CALIBRATING);
    Logger::printComment("Warte auf IMU-Kalibrierung... (Gyro und Accel Stufe 2)");
    Logger::printHeader();
}

// ------------------------------------------------------------
// Hauptschleife
// ------------------------------------------------------------

void loop() {
    // --- Timing ---
    static unsigned long prevMs = 0;
    unsigned long nowMs = millis();
    unsigned long elapsedMs = nowMs - prevMs;

    // LED-Zustandsanzeige jeden Durchlauf aktualisieren (billig, headless wichtig)
    updateStateLed(nowMs);

    // Regelzyklus einhalten: nicht vor LOOP_PERIOD_MS
    if (elapsedMs < LOOP_PERIOD_MS) return;
    float dt = (float)elapsedMs / 1000.0f; // [s]
    prevMs = nowMs;

    // --- Serial-Befehle lesen ---
    char cmd = readSerialCommand();
    if (cmd == 'h') { Logger::printHeader(); }
    if (cmd == 'p') { printParams(); }

    // --- IMU immer lesen (fuer Sicherheitscheck) ---
    imu.update();
    float pitch = imu.pitch();

    // --- Encoder lesen ---
    enc.update(dt);

    // ============================================================
    // Zustandsmaschine
    // ============================================================
    switch (currentState) {

        // ---------------------------------------------------------
        case State::INIT:
            // Sollte nach setup() nicht mehr auftreten -- Fallback wie E_STOP
            if (cmd == 'r') {
                if (tryReinit()) {
                    changeState(State::CALIBRATING);
                } else {
                    Logger::printComment("FEHLER: Reset fehlgeschlagen");
                }
            }
            break;

        // ---------------------------------------------------------
        case State::CALIBRATING: {
            static unsigned long calibratingSinceMs = 0;
            if (calibratingSinceMs == 0) calibratingSinceMs = nowMs;

            // Voll kalibriert ODER Timeout mit wenigstens Gyro-Kalibrierung
            // (Accel-Kalibrierung gelingt headless oft nicht, s. config.h)
            bool fullyCalibrated  = imu.isCalibrated();
            bool timeoutFallback  = (nowMs - calibratingSinceMs) >= CALIB_TIMEOUT_MS
                                    && imu.gyroCalibrated();

            if ((fullyCalibrated || timeoutFallback) && abs(pitch) < RECOVERY_ANGLE_DEG) {
                Logger::printComment(fullyCalibrated
                    ? "IMU kalibriert. Aufrecht hinstellen zum Auto-Arm ('s' = sofort)."
                    : "WARNUNG: Accel unkalibriert (Timeout) -- fahre mit Gyro fort.");
                calibratingSinceMs = 0;
                autoArm.reset();
                changeState(State::IDLE);
            }
            break;
        }

        // ---------------------------------------------------------
        case State::IDLE: {
            motors.stop();

            // Auto-Arm: aufrecht + ruhig fuer AUTOARM_STABLE_MS --> los
            bool armed = autoArm.update(pitch, imu.pitchRate(), nowMs);

            // Manueller Start bleibt als Override erhalten
            bool manualStart = (cmd == 's');
            if (manualStart && abs(pitch) >= RECOVERY_ANGLE_DEG) {
                Logger::printComment("FEHLER: Zu grosser Startwinkel -- aufrecht hinstellen!");
                manualStart = false;
            }

            if (armed || manualStart) {
                Logger::printComment(armed ? "Auto-Arm --> BALANCING" : "Manueller Start --> BALANCING");
                startBalancing();
                break;
            }

            if (abs(pitch) > FALLEN_ANGLE_DEG) {
                autoArm.reset();
                changeState(State::FALLEN);
            }
            break;
        }

        // ---------------------------------------------------------
        case State::BALANCING: {
            // --- SafetySupervisor: Tilt, Overrun, IMU-Stale, Saettigung ---
            // Laeuft VOR der neuen Stellgroesse; duty = zuletzt angewendeter Wert
            SafetyVerdict verdict = safety.check(
                pitch, imu.pitchRate(), elapsedMs, motors.lastDuty(), nowMs);
            if (verdict != SafetyVerdict::OK) {
                motors.stop();
                switch (verdict) {
                    case SafetyVerdict::FALLEN_TILT:
                        changeState(State::FALLEN);
                        break;
                    case SafetyVerdict::FALLEN_SATURATION:
                        Logger::printComment("SICHERHEIT: Duty dauerhaft am Anschlag --> FALLEN");
                        changeState(State::FALLEN);
                        break;
                    case SafetyVerdict::ESTOP_IMU_STALE:
                        Logger::printComment("SICHERHEIT: IMU eingefroren --> E_STOP");
                        changeState(State::E_STOP);
                        break;
                    case SafetyVerdict::ESTOP_LOOP_OVERRUN:
                        Logger::printComment("SICHERHEIT: Loop-Overrun --> E_STOP");
                        changeState(State::E_STOP);
                        break;
                    default:
                        break;
                }
                break;
            }

            // --- Quit-Befehl (manueller Override) ---
            if (cmd == 'q') {
                motors.stop();
                autoArm.reset();
                changeState(State::IDLE);
                break;
            }

            // --- Aeusserer Regler: Position --> Winkel-Sollwert ---
            // TODO: Positionsregler erst aktivieren wenn Winkelregler stabil ist!
            // Vorlaeufig: Winkel-Sollwert zur Laufzeit trimmbar ("Sp=1.5")
            float angleSp = setpointAngleDeg;
            // Wenn Positionsregler aktiv (KP_POS > 0):
            // float posError = 0.0f - enc.positionM();  // Soll: an Ort bleiben
            // float posCorrection = pidPos.compute(posError, dt);
            // angleSp = setpointAngleDeg + posCorrection;

            // --- Innerer Regler: Winkel --> Duty ---
            // D-Anteil aus der gemessenen Gyro-Rate (Phase C):
            // error = sp - pitch, sp quasi konstant --> d(error)/dt = -pitchRate
            float angleError = angleSp - pitch;
            float duty_f     = pidAngle.compute(angleError, -imu.pitchRate(), dt);
            int   duty       = (int)duty_f;

            // --- Motoren ansteuern ---
            motors.setDrive(duty);

            // Kein checkStall() hier: hoher Duty bei ~0 Radgeschwindigkeit
            // ist beim Balancieren legitim. Festhaenger faengt der
            // Saettigungs-Timeout des SafetySupervisors ab.

            // --- Logging ---
            Logger::printData(
                nowMs,
                currentState,
                pitch,
                imu.pitchRate(),
                pidAngle.pTerm(),
                pidAngle.iTerm(),
                pidAngle.dTerm(),
                motors.lastDuty(),
                enc.position(),
                enc.positionM()
            );
            break;
        }

        // ---------------------------------------------------------
        case State::FALLEN:
            motors.stop();

            if (fallenStartMs == 0) {
                fallenStartMs = nowMs; // Eintrittszeit merken
            }

            // Warten bis Wartezeit abgelaufen und Bot aufgerichtet
            if ((nowMs - fallenStartMs) >= FALLEN_WAIT_MS) {
                if (abs(pitch) < RECOVERY_ANGLE_DEG) {
                    fallenStartMs = 0;
                    pidAngle.reset();
                    autoArm.reset();
                    changeState(State::IDLE); // Auto-Arm uebernimmt von hier
                }
            }
            break;

        // ---------------------------------------------------------
        case State::E_STOP:
            // Motoren AUS -- bleibt hier bis manueller Reset ('r').
            // Bewusst KEIN Auto-Recovery: E_STOP-Ursachen sind Anomalien
            // (IMU-Ausfall, Overrun), die ein Mensch pruefen soll.
            motors.stop();

            if (cmd == 'r') {
                // Direkter Neuinitialisierungs-Versuch (frueher: doppeltes 'r'
                // noetig, weil erst nach INIT gewechselt wurde)
                if (tryReinit()) {
                    changeState(State::CALIBRATING);
                } else {
                    Logger::printComment("FEHLER: Reset fehlgeschlagen");
                }
            }
            break;
    }
}

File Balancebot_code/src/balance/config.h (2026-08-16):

#pragma once

// ============================================================
// config.h -- BalanceBot: Alle konfigurierbaren Parameter
//
// Alle Tuning-Parameter, Schwellwerte und Systemkonstanten
// stehen hier zentral. Nichts davon soll im Steuercode
// als Magic Number auftauchen.
// ============================================================

// ------------------------------------------------------------
// Mechanik
// ------------------------------------------------------------

// Raddurchmesser [m]
constexpr float WHEEL_DIAMETER_M       = 0.090f;
// Radradius [m]
constexpr float WHEEL_RADIUS_M         = WHEEL_DIAMETER_M / 2.0f;
// Radumfang [m]
constexpr float WHEEL_CIRCUMFERENCE_M  = 3.14159265f * WHEEL_DIAMETER_M;

// Encoder-Ticks pro Radumdrehung (inkl. 100:1 Getriebe, Quadratur)
constexpr int   COUNTS_PER_WHEEL_REV   = 1200;
// Meter pro Count
constexpr float METERS_PER_COUNT       = WHEEL_CIRCUMFERENCE_M / COUNTS_PER_WHEEL_REV;

// Schwerpunkthoehe ueber Achsmitte [m]
// Gemessen 2026-08-09 per Auslenkungsmethode: 7.6 +- 0.9 mm
// (vorher 30 mm geschaetzt -- die Schaetzung war um Faktor 4 zu gross).
// Details: messungen/results/phase4_cog_20260809.md
// Hinweis: Die Konstante wird im Steuercode derzeit nicht verwendet, sie
// dokumentiert den Modellparameter. Rechnung laeuft ueber python/system_id.py.
constexpr float COG_HEIGHT_M           = 0.0076f;

// Gesamtmasse [kg]
// Gewogen 2026-08-09: 190 g (vorheriger Wert 204 g, Aufbau seither geaendert)
constexpr float TOTAL_MASS_KG          = 0.190f;

// ------------------------------------------------------------
// Abtastzeit
// ------------------------------------------------------------

// Soll-Abtastzeit der Regelschleife [ms]
// 10 ms = 100 Hz. Nicht unter 10 ms gehen (Bandbreite des inversen Pendels)
constexpr unsigned long LOOP_PERIOD_MS = 10;

// ------------------------------------------------------------
// Motoren / Leistungselektronik
// ------------------------------------------------------------

// Maximaler Duty-Cycle [%]
// Motorstall: 1.03 A, Treibergrenze: 0.50 A
// 0.50 / 1.03 * 100 = 48.5 %  --> konservativ auf 45 % begrenzt
// Waehrend der ersten Inbetriebnahme: noch konservativer beginnen (z.B. 30)
constexpr int   MAX_DUTY               = 45;

// Mindest-Duty fuer Loslaufen (Totzone-Kompensation) [%]
// Gemessen 2026-08-07 bei 3.57 V (deadzone_id): Anlauf 23 % auf der
// positiven, 16-17 % auf der negativen Duty-Seite (beide Motoren gleich
// -- Asymmetrie liegt im Carrier-Treiber). Kompensation deshalb getrennt
// pro Duty-Vorzeichen, angewendet pro Motor-Anschluss (deadzone.h).
// Details: messungen/results/phase3_deadzone_20260807.md
constexpr int   DEADZONE_DUTY_POS      = 23;
constexpr int   DEADZONE_DUTY_NEG      = 17;

// Maximale Aenderung des Duty-Cycles pro Abtastschritt (Slew-Rate) [%/Schritt]
constexpr int   DUTY_SLEW_RATE         = 20;

// Stall-Erkennung:
// Wenn abs(duty) >= STALL_DUTY_THRESHOLD und abs(speed) <= STALL_SPEED_THRESHOLD
// fuer STALL_TIMEOUT_MS ms --> E_STOP ausloesen
constexpr int   STALL_DUTY_THRESHOLD   = 30;    // Duty-Wert ab dem Stall moeglich
constexpr int   STALL_SPEED_THRESHOLD  = 5;     // Encoder-Counts/s unter denen "zu langsam"
constexpr int   STALL_TIMEOUT_MS       = 500;   // Zeit bis Stall-E_STOP [ms]

// ------------------------------------------------------------
// Zustandsmaschine / Sicherheit
// ------------------------------------------------------------

// Sicherheits-Kippwinkel [Grad]
// Ueber diesem Winkel gilt der Bot als "gefallen" --> FALLEN-Zustand
constexpr float FALLEN_ANGLE_DEG       = 45.0f;

// Winkel fuer Rueckkehr aus FALLEN nach IDLE [Grad]
// Bot muss unter diesem Winkel stehen, bevor Motoren wieder aktiv werden
constexpr float RECOVERY_ANGLE_DEG     = 15.0f;

// Wartezeit nach FALLEN vor erneutem Versuch [ms]
constexpr unsigned long FALLEN_WAIT_MS = 1000;

// ------------------------------------------------------------
// Headless-Betrieb / Auto-Arm (Phase A)
// ------------------------------------------------------------

// Maximale Wartezeit auf Serial-Verbindung beim Boot [ms]
// Danach startet die Firmware headless (Akku-Betrieb ohne PC)
constexpr unsigned long SERIAL_WAIT_MS     = 1500;

// Auto-Arm: Bot armiert selbst, wenn er aufrecht und ruhig gehalten wird.
// Winkel- und Raten-Fenster muessen AUTOARM_STABLE_MS lang
// ununterbrochen eingehalten sein.
constexpr float         AUTOARM_ANGLE_DEG  = 6.0f;   // [Grad]
constexpr float         AUTOARM_RATE_DPS   = 20.0f;  // [Grad/s]
constexpr unsigned long AUTOARM_STABLE_MS  = 800;    // [ms]
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

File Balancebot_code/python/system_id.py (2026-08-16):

"""
system_id.py -- BalanceBot: Systemmodell und Regler-Startwerte (Phase 5)

Berechnet aus den physikalischen Parametern:
  1. Eigenfrequenz omega_0 des inversen Pendels
  2. Linearisiertes Zustandsraummodell (A, B) fuer [theta, theta_dot]
  3. Offene-Kreis-Eigenwerte (ein instabiler Pol erwartet)
  4. PD-Startwerte fuer die Firmware (Kp, Kd in Duty%/Grad-Einheiten)
     per Polvorgabe (Daempfung zeta, Bandbreite omega_c = k * omega_0)

Benutzung:
    python python/system_id.py                       # mit CAD-Prior L = 8.6 mm
    python python/system_id.py --L-mm 12.5           # Koerper-L direkt vorgeben
    # Nach Knife-Edge-Messung (Phase 4, misst GESAMT-CoM inkl. Raeder):
    python python/system_id.py --total-com-mm 6.2 --com-offset-mm -1.0

Alle Formeln mit Parametertabellen: dokumentation/auslegung/system_model.md
"""

import argparse

import numpy as np

# ============================================================
# Parameter (Quelle: Messung / Datenblatt / CAD)
# ============================================================

# Mechanik
TOTAL_MASS_KG   = 0.190    # gewogen 2026-08-09, inkl. Raeder (vorher 0.204)
WHEEL_MASS_KG   = 0.044    # gewogen 2026-08-09, beide Raeder zusammen.
                           # CAD sagte 2 x 33.65 = 67.3 g -- die alte Baugruppe
                           # ist hier deutlich zu schwer, deshalb nur wiegen.
WHEEL_RADIUS_M  = 0.045
G_M_S2          = 9.81

# CoG-Hoehe des KOERPERS (ohne Raeder) ueber der Achse.
# CAD-Prior 2026-04-12 (ohne Kabel/Schrauben, ~50 g fehlen): 8.6 mm
# --> Nach Knife-Edge-Messung (Phase 4) per --L-mm ueberschreiben!
DEFAULT_L_MM    = 8.6

# Motor/Treiber (Herleitung siehe dokumentation/auslegung/system_model.md)
KT_EFF_NM_A     = 0.0215   # Drehmomentkonstante nach Getriebe [N*m/A]
RA_OHM          = 11.65    # Ankerwiderstand [Ohm]
N_MOTORS        = 2
DEFAULT_VBAT_V  = 3.7      # nominale Akkuspannung [V]

# Regelung
LOOP_PERIOD_MS  = 10.0     # Abtastperiode der Firmware (config.h LOOP_PERIOD_MS)

# Bekannte Totzeitanteile der Regelkette [ms]:
#   Abtastung 10.0 (LOOP_PERIOD_MS) + Halteglied 5.0 (halbe Periode)
#   + I2C-Verkehr 6.4 (Phase-1-Messung, Mittelwert)
# Die interne Fusionsverzoegerung des BNO055 kommt obendrauf und ist nicht
# vermessen -- der reale Wert liegt also ueber diesem Default.
DEFAULT_DELAY_MS = 21.4

# Regelziel
ZETA            = 0.7      # Daempfungsgrad der Sollpole
BW_FACTOR       = 2.0      # omega_c = BW_FACTOR * omega_0
MAX_DUTY        = 45       # Firmware-Grenze [%]


def build_model(l_m: float, vbat: float, pole: float = None):
    """Vereinfachtes 2-Zustands-Modell [theta, theta_dot], Eingang duty%.

    Koerper als Pendel um die Radachse:
      J_b * theta_dd = m_b*g*L*theta - tau      (linearisiert, tau = Radmoment)
    Duty -> Moment (Stall-Naeherung, omega ~ 0 beim Balancieren):
      tau(duty%) = N * Kt_eff * (duty/100 * vbat) / Ra

    J_b kommt aus einer von zwei Quellen:

    a) pole gegeben (Schwingversuch, Phase 4 Messung 3) -- der bevorzugte Weg.
       Haengender und aufrechter Bot haben denselben |Eigenwert|, also gilt
       J = m_b*g*L / p^2 mit dem gemessenen p. Keine Annahme noetig.

    b) pole = None -- Rueckfall auf die Punktmasse-Naeherung 1.2*m*L^2.
       ACHTUNG: Die unterschaetzt J erheblich, sobald Masse weit von der
       Achse sitzt (2026-08-09 am Bot gemessen: Faktor ~6 zu klein).
    """
    m_body = TOTAL_MASS_KG - WHEEL_MASS_KG

    if pole is not None:
        j_body = m_body * G_M_S2 * l_m / pole**2
    else:
        j_body = 1.2 * m_body * l_m**2      # Punktmasse + 20% Verteilungszuschlag

    tau_per_duty = N_MOTORS * KT_EFF_NM_A * (vbat / 100.0) / RA_OHM  # [N*m / %]
    b = tau_per_duty / j_body               # [rad/s^2 pro Duty-%]

    a21 = m_body * G_M_S2 * l_m / j_body    # = p^2

    # Bandbreitenbezug: der tatsaechliche instabile Pol, nicht sqrt(g/L).
    # Bei gemessenem J fallen die beiden ohnehin zusammen (a21 = p^2).
    omega0 = np.sqrt(a21)

    A = np.array([[0.0, 1.0],
                  [a21, 0.0]])
    B = np.array([[0.0],
                  [-b]])                    # positives Duty faehrt vorwaerts,
                                            # wirkt negativ auf theta_dd
    return A, B, omega0, b, m_body, j_body


def pd_gains(a21: float, b: float, omega0: float):
    """PD-Startwerte per Polvorgabe.

    Geschlossener Kreis mit duty = Kp*e + Kd*de (e = -theta):
      theta_dd = (a21 - b*Kp_rad)*theta - b*Kd_rad*theta_dot
    Sollpolynom: s^2 + 2*zeta*omega_c*s + omega_c^2
    """
    omega_c = BW_FACTOR * omega0
    kp_rad = (a21 + omega_c**2) / b          # [%/rad]
    kd_rad = 2.0 * ZETA * omega_c / b        # [%/(rad/s)]
    deg = np.pi / 180.0
    return kp_rad * deg, kd_rad * deg, omega_c


def _bisect(f, lo: float, hi: float, n: int = 200) -> float:
    """Nullstelle durch Intervallhalbierung -- vermeidet eine scipy-Abhaengigkeit."""
    f_lo = f(lo)
    for _ in range(n):
        mid = 0.5 * (lo + hi)
        f_mid = f(mid)
        if (f_lo < 0) == (f_mid < 0):
            lo, f_lo = mid, f_mid
        else:
            hi = mid
    return 0.5 * (lo + hi)


def critical_delay(a21: float, b: float, kp_deg: float, kd_deg: float):
    """Kleinste Totzeit, bei der der geschlossene Kreis marginal stabil wird.

    Das Modell in build_model() kennt keine Totzeit. Die reale Kette hat aber
    welche: Abtastung, Halteglied, I2C-Verkehr und die interne Fusion des
    BNO055. Totzeit dreht Phase, und weil die Strecke einen instabilen Pol
    hat, ist die Phasenreserve von vornherein knapp.

    Charakteristische Gleichung mit Totzeit T:
        s^2 - a21 + b*(Kp_rad + Kd_rad*s) * exp(-s*T) = 0

    Marginal stabil heisst s = j*w. Aufgeteilt nach Real- und Imaginaerteil:
        Im:  Kd_rad*w*cos(w*T) - Kp_rad*sin(w*T) = 0   ->  w*T = atan(Kd_rad*w/Kp_rad)
        Re: -w^2 - a21 + b*(Kp_rad*cos(w*T) + Kd_rad*w*sin(w*T)) = 0

    Die erste Gleichung liefert die Phase, Einsetzen in die zweite ergibt eine
    Gleichung allein in w. Rueckgabe: (T_krit [s], Schwingfrequenz [Hz]).
    """
    deg = np.pi / 180.0
    kp, kd = kp_deg / deg, kd_deg / deg

    def residual(w):
        phase = np.arctan2(kd * w, kp)
        return -w * w - a21 + b * (kp * np.cos(phase) + kd * w * np.sin(phase))

    w = _bisect(residual, 1.0, 600.0)
    return float(np.arctan2(kd * w, kp) / w), float(w / (2 * np.pi))
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

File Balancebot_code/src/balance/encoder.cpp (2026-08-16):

// ============================================================
// encoder.cpp -- BalanceBot: Encoder-Implementierung
// ============================================================

#include "encoder.h"
#include "config.h"
#include <ArduinoMotorCarrier.h>

void Encoder::begin() {
    encoder1.resetCounter(0);
    encoder2.resetCounter(0);
    _position = 0;
    _speedCps = 0;
    _prevPos  = 0;
}

void Encoder::update(float dt) {
    // Rohe Encoder-Counts lesen
    int raw1 = encoder1.getRawCount(); // positiv bei Vorwaertsfahrt (hw_check 2026-08-07)
    int raw2 = encoder2.getRawCount(); // negativ bei Vorwaertsfahrt

    // Gemittelte Position (positiv = vorwaerts)
    // Formel: (enc1 - enc2) / 2 hebt die gegenlaeufige Montage auf
    _position = (raw1 - raw2) / 2;

    // Geschwindigkeit als Ableitung der Position [Counts/s]
    // Schutz vor dt = 0 (sollte durch Hauptschleife verhindert sein)
    if (dt > 0.0f) {
        int deltaPos = _position - _prevPos;
        _speedCps = (int)((float)deltaPos / dt);
    }
    _prevPos = _position;
}

float Encoder::positionM() const {
    return (float)_position * METERS_PER_COUNT;
}

void Encoder::reset() {
    encoder1.resetCounter(0);
    encoder2.resetCounter(0);
    _position = 0;
    _speedCps = 0;
    _prevPos  = 0;
}

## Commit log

2026-08-16 chore: sync firmware and CAD from private repo at b8400ac
    [Pololu 90mm Wheel.dwg, Pololu_Wheel_90x10.FCStd, Samsung INR18650-25R.stp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]
2026-08-16 chore: sync firmware and CAD from private repo at 4a08de1
2026-08-16 chore: sync firmware and CAD from private repo at c421564
2026-08-16 chore: sync firmware and CAD from private repo at ae50e54
2026-08-16 chore: sync firmware and CAD from private repo at ca3e6d4
2026-08-16 chore: sync firmware and CAD from private repo at 8351bde
2026-08-16 chore: sync firmware and CAD from private repo at 598a39f
    [Pololu_Wheel_90x10.FCStd]
2026-08-17 chore: sync firmware and CAD from private repo at 887abb1
